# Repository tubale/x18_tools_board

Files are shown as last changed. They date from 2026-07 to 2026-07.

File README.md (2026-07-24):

# ROV Tools Board

A custom **4-layer STM32-based PCB** designed for Purdue IEEE Underwater Robotics to control a six-servo robotic arm. This project involved the complete hardware development cycle, including system architecture, schematic design, PCB layout, power distribution, board bring-up, debugging, and integration into the ROV.

---

## Overview

The Tools Board serves as the interface between the Raspberry Pi and the ROV's robotic arm. It provides reliable power delivery, real-time servo control, and SPI communication while operating in a high-current, electrically noisy environment.

This project was designed from the ground up using KiCad and assembled, tested, and validated on the team's underwater robot.

---

## Features

- Custom **4-layer PCB** designed in **KiCad**
- **STM32 microcontroller** for real-time control
- Controls **6 independent servo motors**
- Supports up to **4A peak current**
- High-efficiency **12V → 6V buck converter**
- **5V → 3.3V LDO** for the STM32 and logic circuitry
- **SPI communication** with Raspberry Pi
- Optimized PCB layout with isolated power planes for improved signal integrity
- Hand assembled and fully validated through hardware bring-up

---

## Hardware Architecture

```text
                 Raspberry Pi
                      │
                   SPI Interface
                      │
              ┌───────────────┐
              │   STM32 MCU   │
              └───────────────┘
          PWM │ │ │ │ │ │
              ▼ ▼ ▼ ▼ ▼ ▼
        ┌────────────────────┐
        │   6 Servo Outputs  │
        └────────────────────┘

12V Input
    │
    ▼
┌──────────────┐
│ Buck 12V→6V  │────────► Servos
└──────────────┘
    │
    ▼
┌──────────────┐
│ LDO 5V→3.3V  │────────► STM32 + Logic
└──────────────┘
```

---

## Design Process

### System Architecture

- Defined power and communication requirements
- Selected STM32 microcontroller
- Designed SPI interface with Raspberry Pi
- Planned high-current power distribution for servo operation

### Schematic Design

Designed the complete electrical schematic including:

- STM32 microcontroller
- Servo outputs
- SPI interface
- Programming/debug connector
- Buck converter
- LDO regulator
- Decoupling and filtering circuitry
- Status LEDs
- Connectors

### PCB Layout

Designed a **4-layer PCB** with:

- Dedicated ground plane
- Dedicated power plane
- High-current routing for servo power
- Short SPI signal paths
- Proper decoupling placement
- Separation between noisy power circuitry and sensitive digital signals

### Assembly

- Soldered surface-mount and through-hole components
- Inspected and verified board assembly
- Performed continuity testing before power-up

### Bring-Up & Validation

Verified each subsystem independently using:

- Digital Multimeter
- Oscilloscope
- Logic Analyzer

Testing included:

- Power rail verification
- SPI communication
- PWM generation
- Servo functionality
- Current measurements
- Signal integrity

---

### Technologies

**Hardware:** KiCad • STM32 • SPI • PWM • 4-Layer PCB Design • Buck Converter Design • LDO Voltage Regulation

**Testing:** Oscilloscope • Logic Analyzer • Digital Multimeter

---

## Gallery

### Schematic

<p align="center">
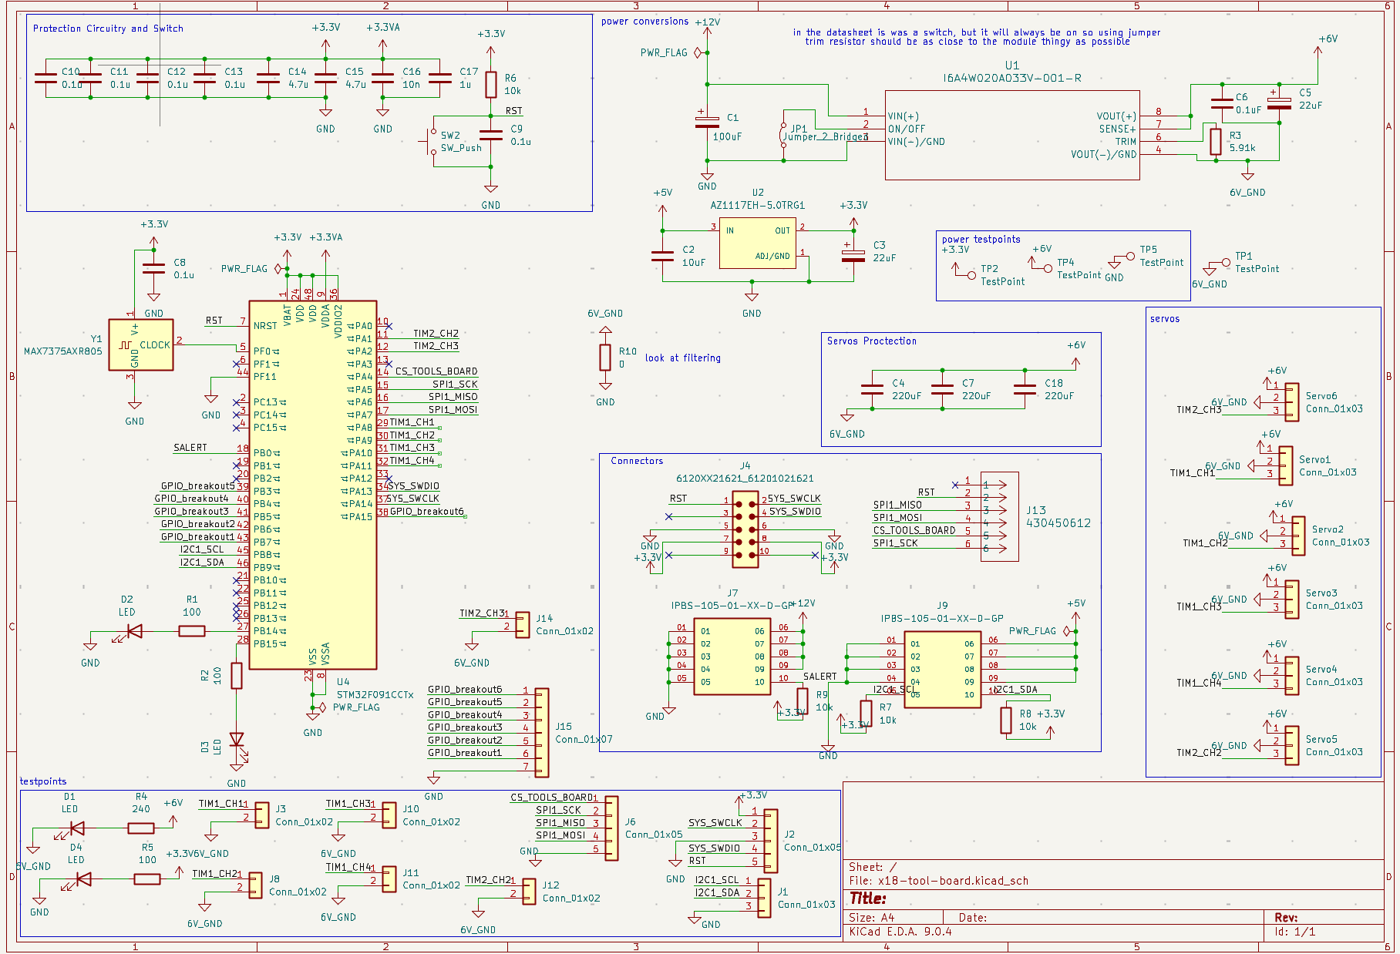
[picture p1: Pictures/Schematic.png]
  
</p>

### Layout

<p align="center">
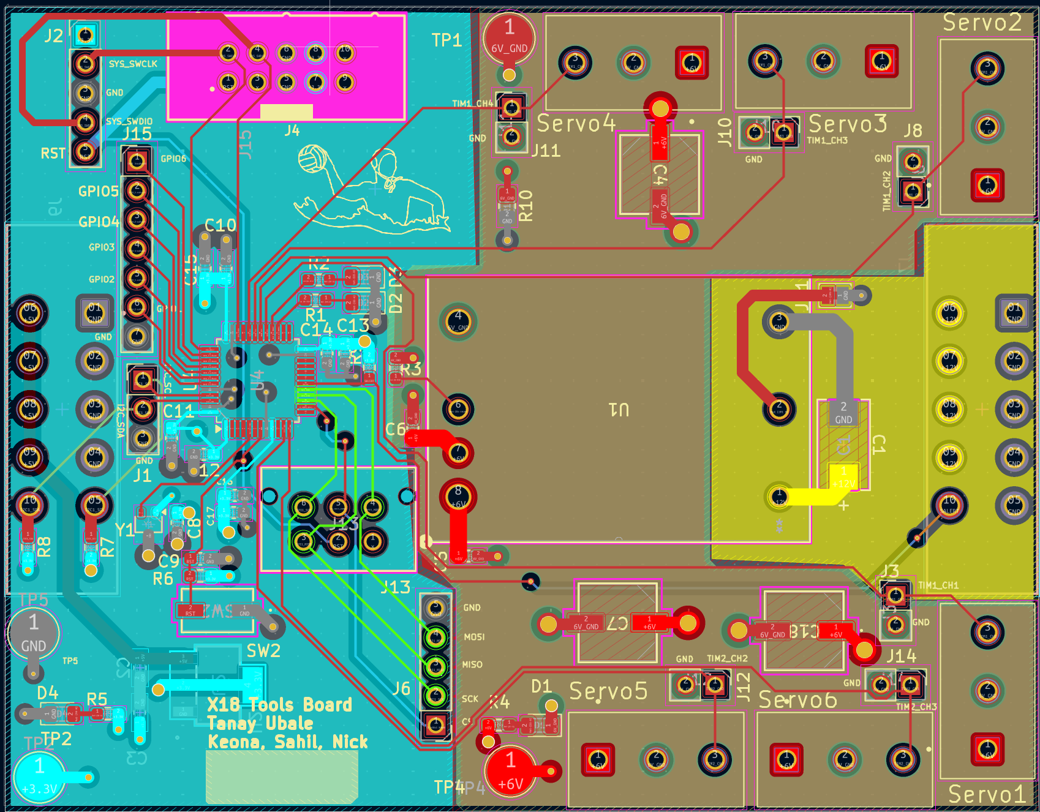
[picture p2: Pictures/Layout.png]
  
</p>

### Assembled Board

<p align="center">
  
</p>

---

## Author

**Tanay Ubale**

Electrical & Computer Engineering Student at Purdue University

Interested in Digital Design, FPGA Development, ASIC Design, Embedded Systems, PCB Design, and Computer Architecture.

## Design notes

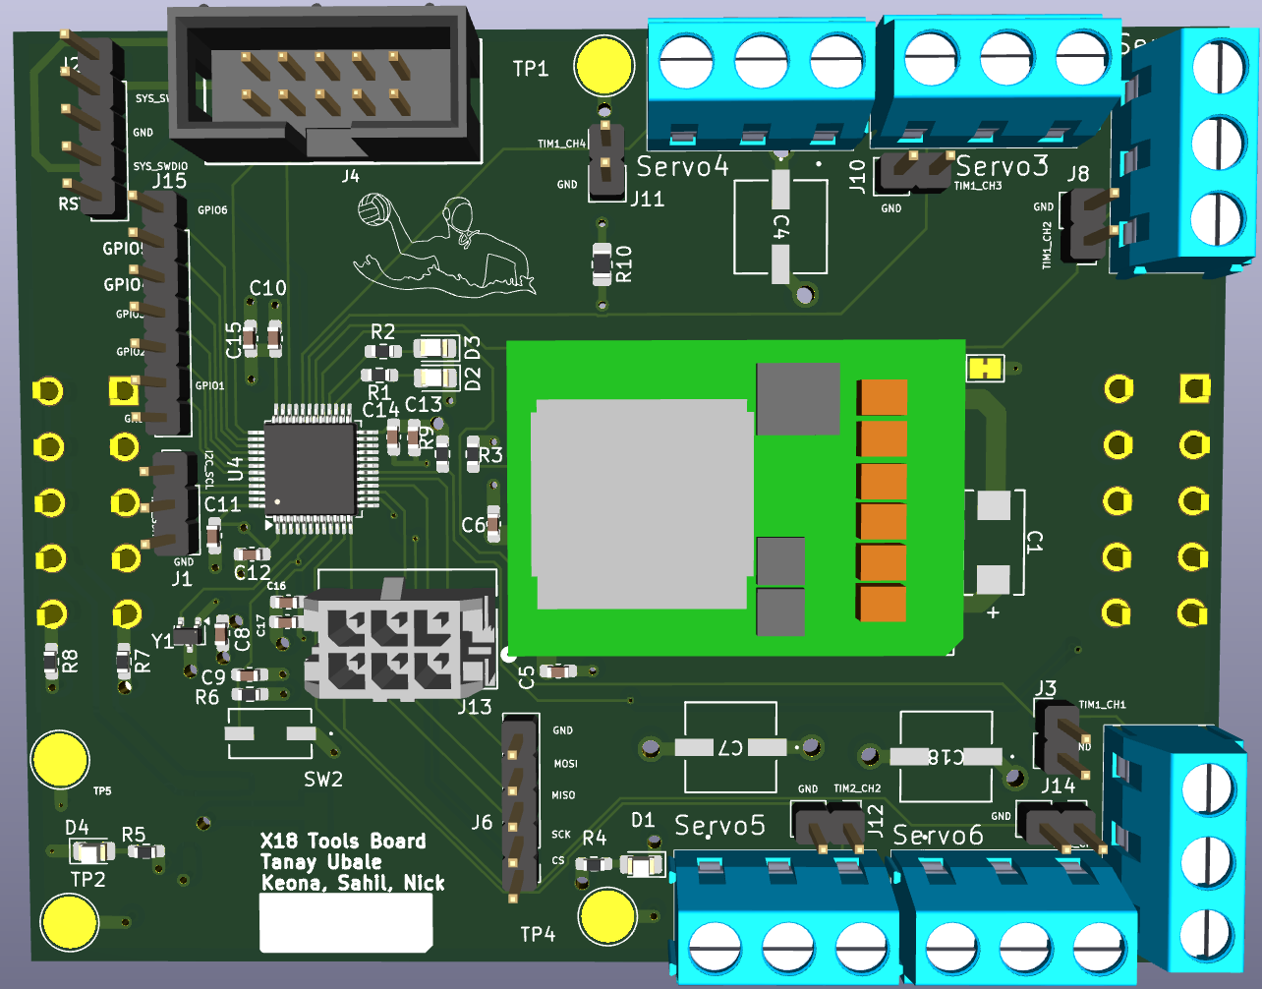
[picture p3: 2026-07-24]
Pictures/3d Model_front.png

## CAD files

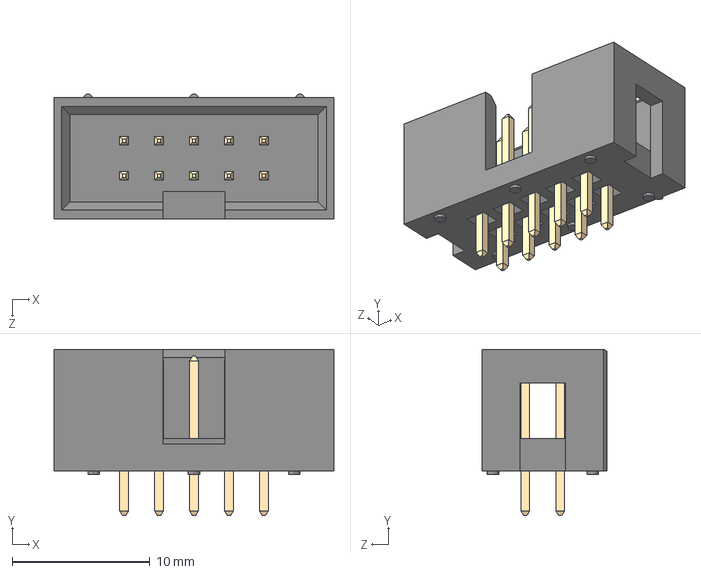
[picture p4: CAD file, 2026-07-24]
Footprints/61201021621/6120XX21621_61201021621.step
20.4 x 12.1 x 9.10 mm

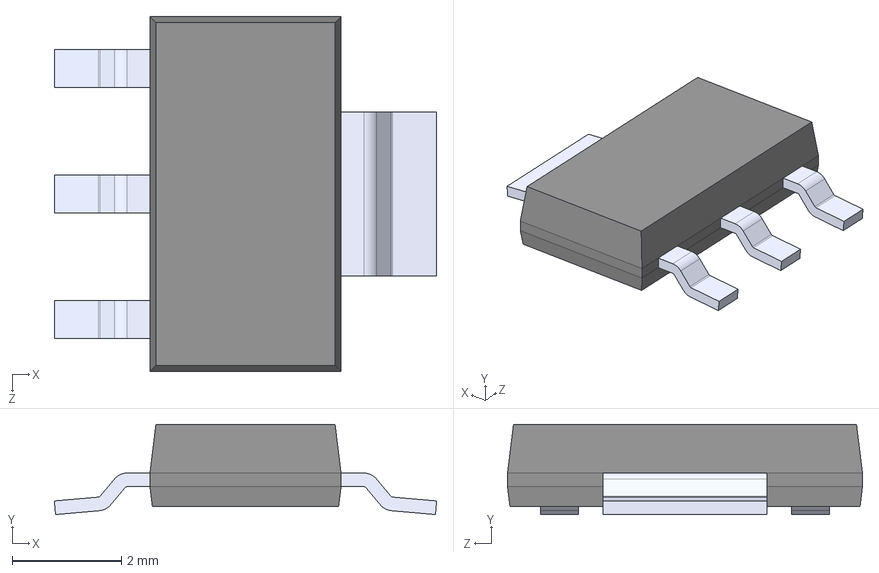
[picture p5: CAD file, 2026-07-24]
Footprints/AZ1117CH_3_3TRG1/AZ1117EH-5.0TRG1/AZ1117EH-5.0TRG1.step
7.00 x 1.65 x 6.50 mm

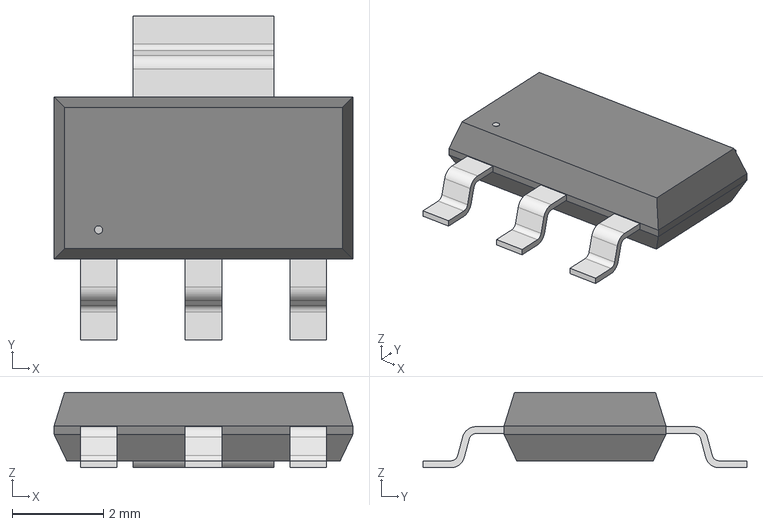
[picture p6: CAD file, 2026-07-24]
Footprints/AZ1117CH_3_3TRG1/SOT-223_DIO.step
6.55 x 7.10 x 1.65 mm

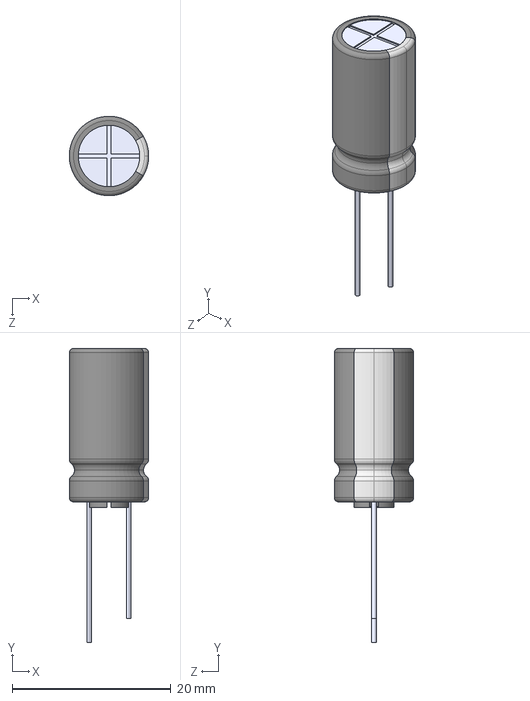
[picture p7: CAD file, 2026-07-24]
Footprints/EEU_FC1H221/EEUFC1H221.step
10.0 x 37.0 x 9.99 mm

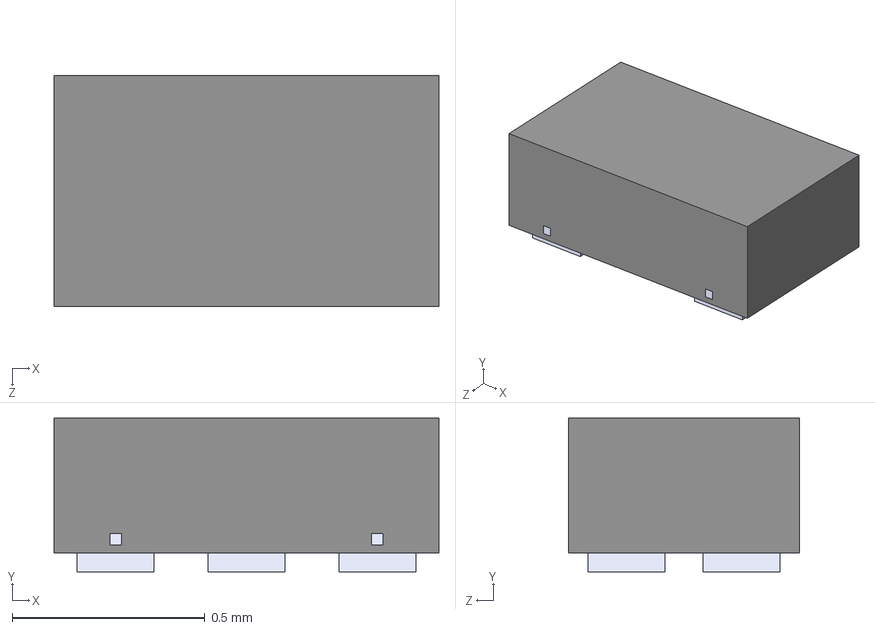
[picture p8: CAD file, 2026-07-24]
Footprints/ESD122DMXR/ESD122DMXR.step
1.00 x 0.4 x 0.6 mm

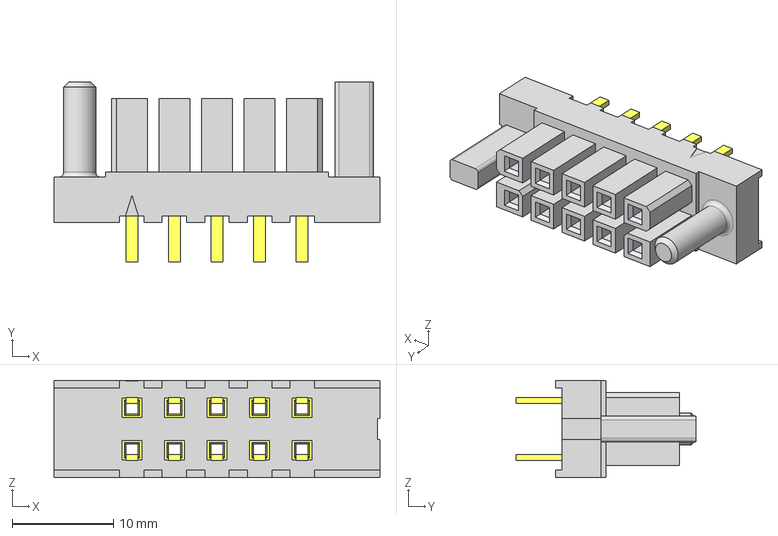
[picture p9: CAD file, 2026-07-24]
Footprints/IPBS-105-01-XX-D-GP/IPBS-105-01-XX-D-GP.step
32.1 x 17.8 x 9.60 mm
IPBS-105-XX-D-GP_socket
C-168-01-05-D

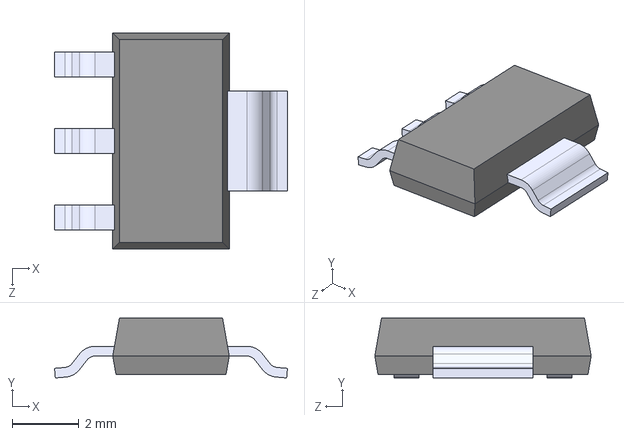
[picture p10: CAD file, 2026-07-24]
Footprints/LM3940/LM3940IMPX-3.3_NOPB.step
7.00 x 1.80 x 6.50 mm

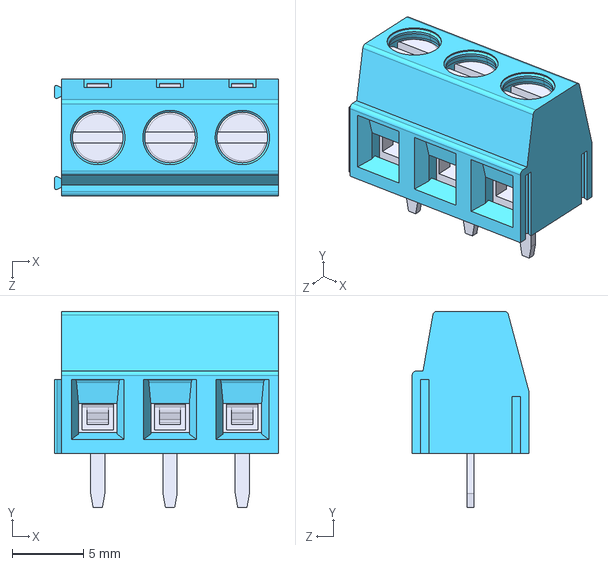
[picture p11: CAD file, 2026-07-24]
Footprints/TB006_508_03BE/TB006-508-03BE.step
15.7 x 13.8 x 8.20 mm

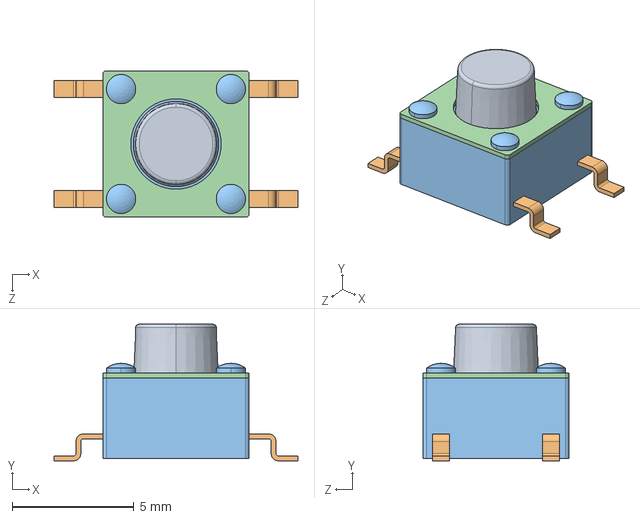
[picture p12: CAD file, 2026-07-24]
Footprints/TS04_66_55_BK_100_SMT/TS04-66-55-BK-100-SMT.step
10.0 x 5.60 x 6.00 mm

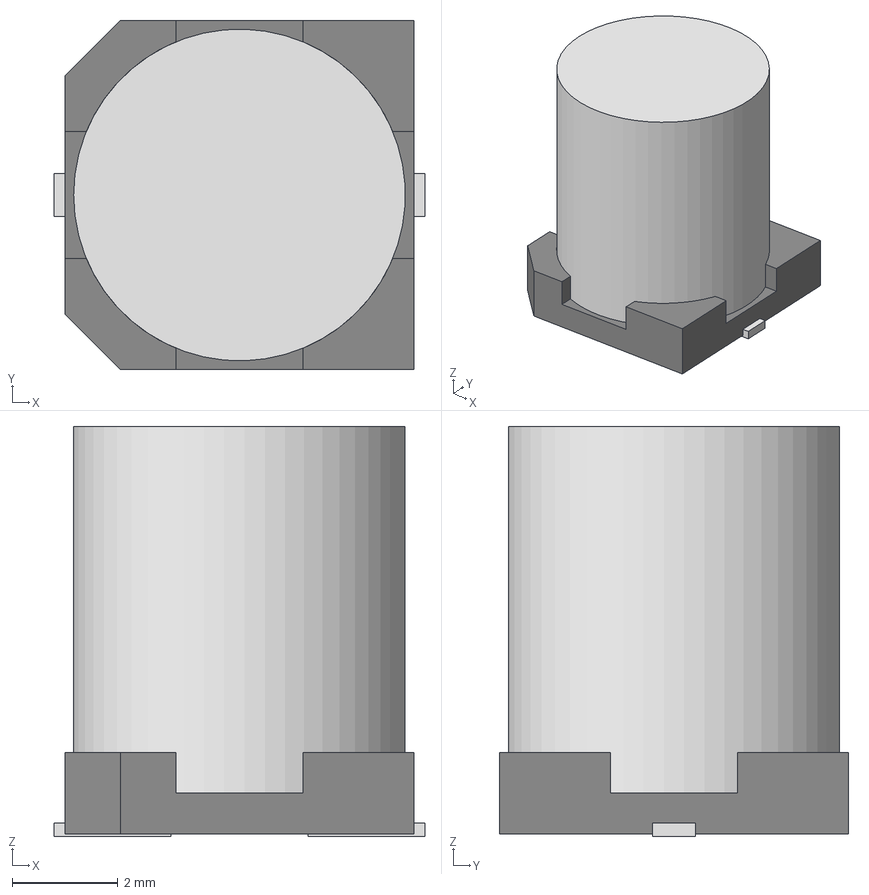
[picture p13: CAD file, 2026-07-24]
Footprints/ul_UWT1C221MCL1GS/U2-K_NCH.step
7.01 x 6.60 x 7.75 mm

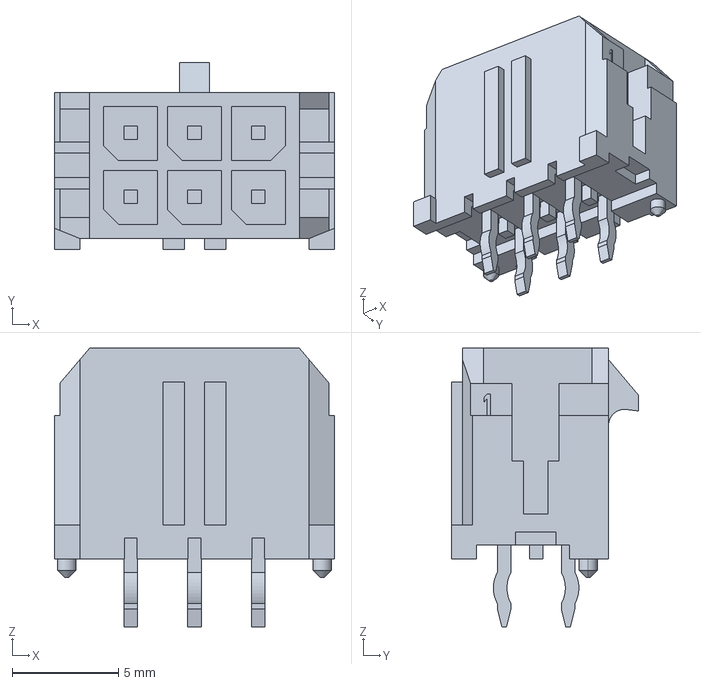
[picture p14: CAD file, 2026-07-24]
Footprints/430450612/430450612.stp
13.2 x 8.77 x 13.1 mm

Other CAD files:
Footprints/430450628/430450628.stp

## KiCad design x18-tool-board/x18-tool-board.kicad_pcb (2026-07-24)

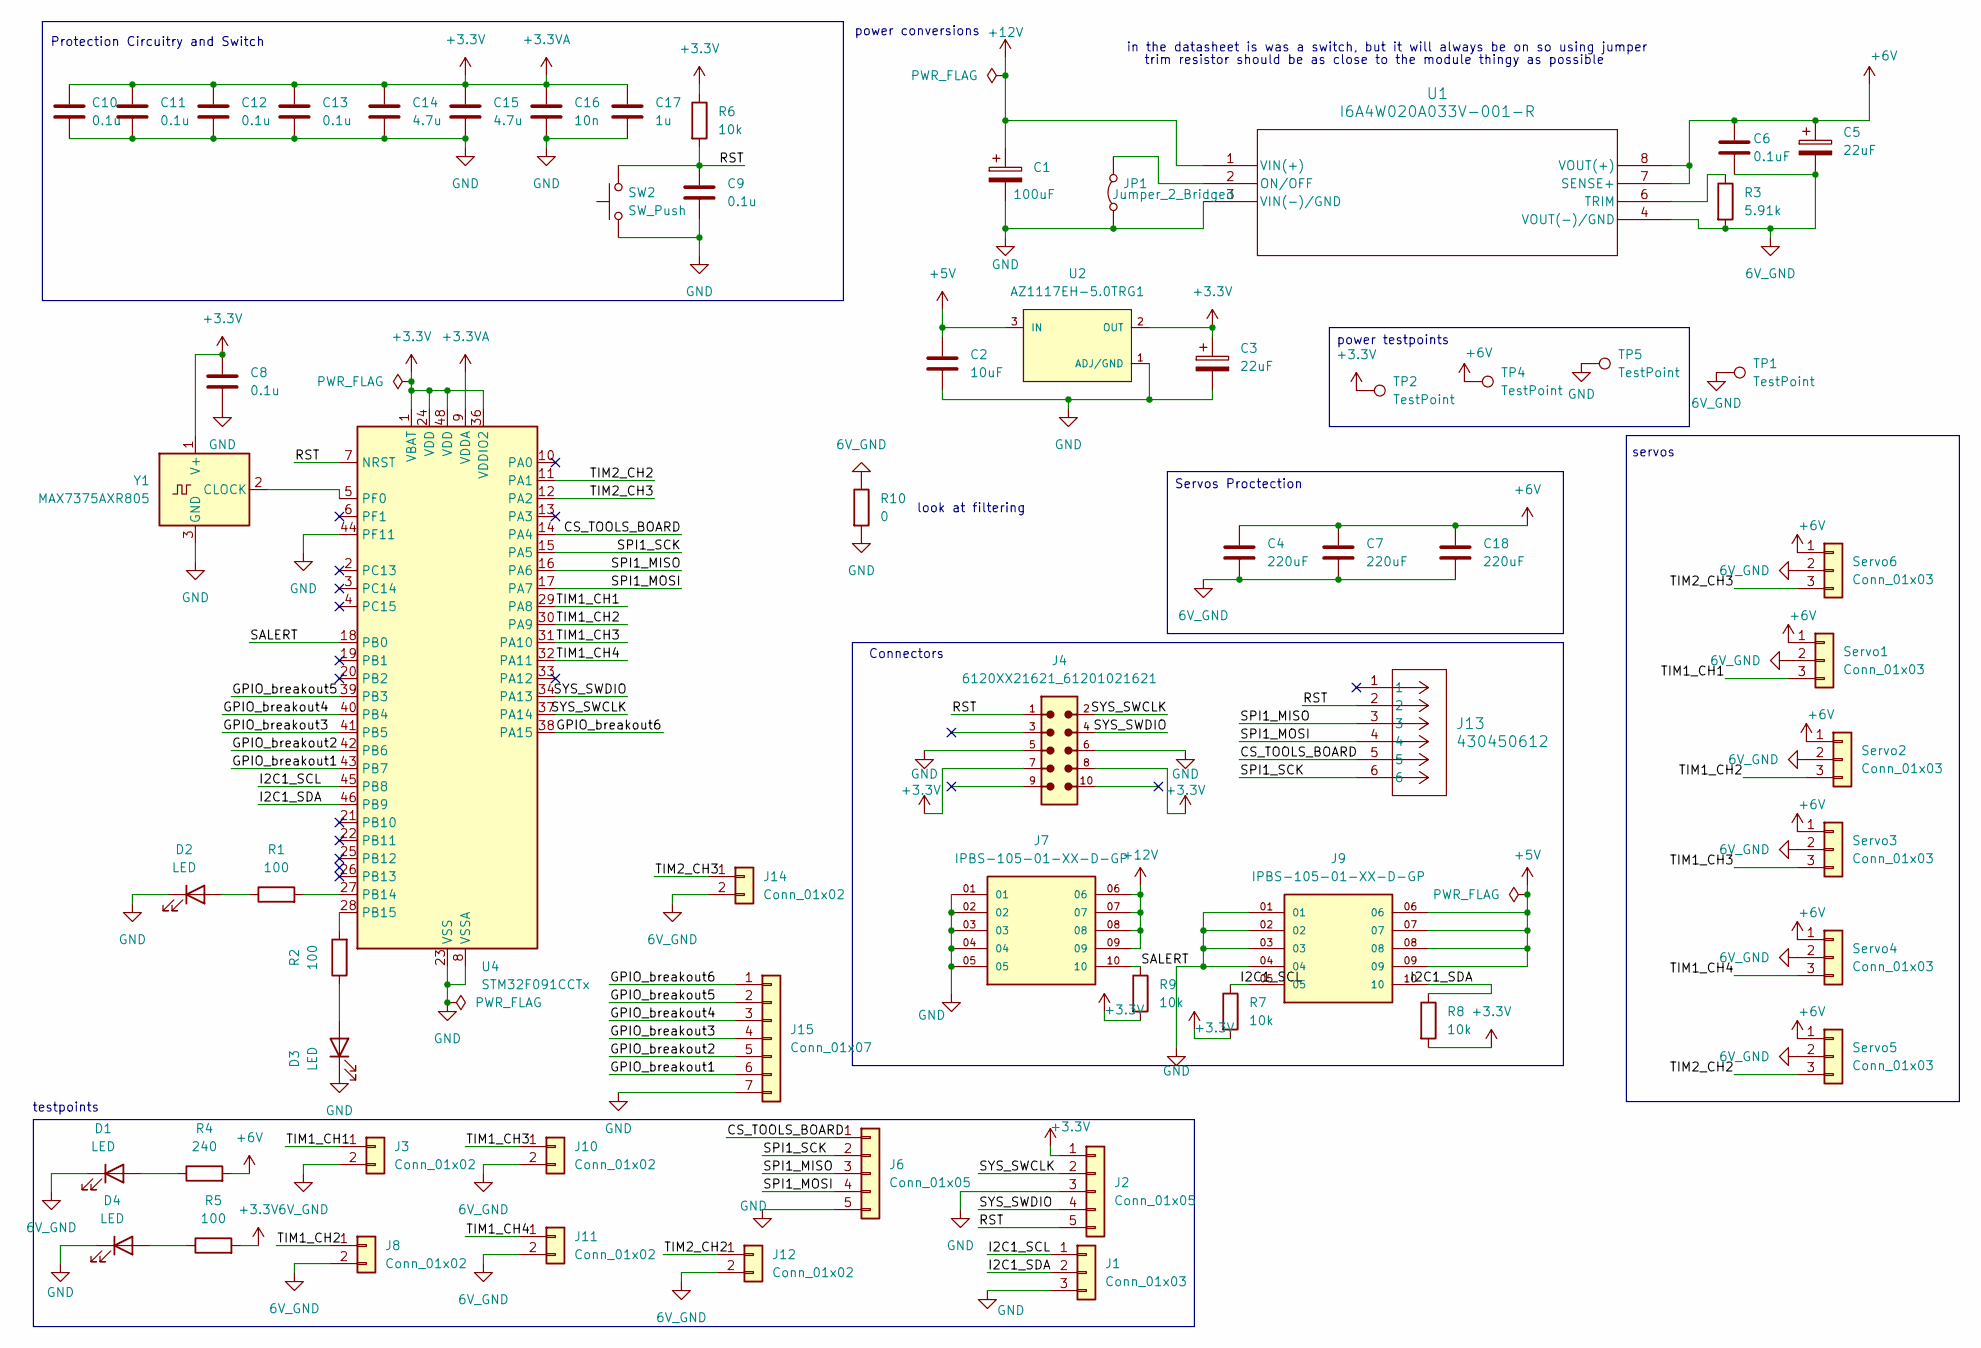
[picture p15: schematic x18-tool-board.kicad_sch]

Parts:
C1: 100uF; CAPMP7.6X4.3_4.3N_KEM-L
C2: 10uF; C_0603_1608Metric_Pad1.08x0.95mm_HandSolder
C3, C5: 22uF; C_0603_1608Metric_Pad1.08x0.95mm_HandSolder
C4, C7, C18: 220uF; U2-K_NCH-M
C6: 0.1uF; C_0603_1608Metric_Pad1.08x0.95mm_HandSolder
C8, C9, C10, C11, C12, C13: 0.1u; C_0603_1608Metric_Pad1.08x0.95mm_HandSolder
C14, C15: 4.7u; C_0603_1608Metric_Pad1.08x0.95mm_HandSolder
C16: 10n; C_0603_1608Metric_Pad1.08x0.95mm_HandSolder
C17: 1u; C_0603_1608Metric_Pad1.08x0.95mm_HandSolder
D1, D2, D3, D4: LED; LED_0805_2012Metric_Pad1.15x1.40mm_HandSolder
J1: Conn_01x03; PinHeader_1x03_P2.54mm_Vertical
J2, J6: Conn_01x05; PinHeader_1x05_P2.54mm_Vertical
J3, J8, J10, J11, J12, J14: Conn_01x02; PinHeader_1x02_P2.54mm_Vertical
J4: 6120XX21621_61201021621; 61201021621
J7, J9: IPBS-105-01-XX-D-GP; SAMTEC_IPBS-105-01-XX-D-GP; PARTREV M
J13: 430450612; CONN_SD-43045-005_06_MOL
J15: Conn_01x07; PinHeader_1x07_P2.54mm_Vertical
JP1: Jumper_2_Bridged; SolderJumper-2_P1.3mm_Bridged_Pad1.0x1.5mm
R1, R2, R5: 100; R_0603_1608Metric_Pad0.98x0.95mm_HandSolder
R3: 5.91k; R_0603_1608Metric_Pad0.98x0.95mm_HandSolder
R4: 240; R_0603_1608Metric_Pad0.98x0.95mm_HandSolder
R6, R7, R8, R9: 10k; R_0603_1608Metric_Pad0.98x0.95mm_HandSolder
R10: 0; R_0805_2012Metric_Pad1.20x1.40mm_HandSolder
SW2: SW_Push; SW_FSM2JMTR_TEC-M
Servo1, Servo2, Servo3, Servo4, Servo5, Servo6: Conn_01x03; CUI_TB006-508-03BE
TP1, TP2, TP4, TP5: TestPoint; TestPoint_Pad_D4.0mm
U1: I6A4W020A033V-001-R; i6A_TDK
U2: AZ1117EH-5.0TRG1; SOT-223_DIO
U4: STM32F091CCTx; LQFP-48_7x7mm_P0.5mm
Y1: MAX7375AXR805; SOT-323_SC-70

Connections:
6V_GND: C4.2, C5.2, C6.2, C7.2, C18.2, D1.1 (K), J3.2, J8.2, J10.2, J11.2, J12.2, J14.2, R3.2, R10.1, Servo1.2, Servo2.2, Servo3.2, Servo4.2, Servo5.2, Servo6.2, TP1.1, U1.4 (VOUT(-)/GND)
+3.3V: C3.1, C8.1, C10.1, C11.1, C12.1, C13.1, C14.1, C15.1, C16.1, C17.1, J2.1, J4.7, J4.8, R5.2, R6.1, R7.2, R8.2, R9.2, TP2.1, U2.2 (OUT), U2.4 (OUT), U4.1 (VBAT), U4.9 (VDDA), U4.24 (VDD), U4.36 (VDDIO2), U4.48 (VDD), Y1.1 (V+)
+5V: C2.1, J9.06, J9.07, J9.08, J9.09, U2.3 (IN)
+6V: C4.1, C5.1, C6.1, C7.1, C18.1, R4.2, Servo1.1, Servo2.1, Servo3.1, Servo4.1, Servo5.1, Servo6.1, TP4.1, U1.7 (SENSE+), U1.8 (VOUT(+))
+12V: C1.1, J7.06, J7.07, J7.08, J7.09, U1.1 (VIN(+))
/CS_TOOLS_BOARD: J6.1, J13.5, U4.14 (PA4)
/GPIO_breakout1: J15.6, U4.43 (PB7)
/GPIO_breakout2: J15.5, U4.42 (PB6)
/GPIO_breakout3: J15.4, U4.41 (PB5)
/GPIO_breakout4: J15.3, U4.40 (PB4)
/GPIO_breakout5: J15.2, U4.39 (PB3)
/GPIO_breakout6: J15.1, U4.38 (PA15)
/I2C1_SCL: J1.1, J9.05, R7.1, U4.45 (PB8)
/I2C1_SDA: J1.2, J9.10, R8.1, U4.46 (PB9)
/RST: C9.1, J2.5, J4.1, J13.2, R6.2, SW2.2, U4.7 (NRST)
/SALERT: J7.10, R9.1, U4.18 (PB0)
/SPI1_MISO: J6.3, J13.3, U4.16 (PA6)
/SPI1_MOSI: J6.4, J13.4, U4.17 (PA7)
/SPI1_SCK: J6.2, J13.6, U4.15 (PA5)
/SYS_SWCLK: J2.2, J4.2, U4.37 (PA14)
/SYS_SWDIO: J2.4, J4.4, U4.34 (PA13)
/TIM1_CH1: J3.1, Servo1.3, U4.29 (PA8)
/TIM1_CH2: J8.1, Servo2.3, U4.30 (PA9)
/TIM1_CH3: J10.1, Servo3.3, U4.31 (PA10)
/TIM1_CH4: J11.1, Servo4.3, U4.32 (PA11)
/TIM2_CH2: J12.1, Servo5.3, U4.11 (PA1)
/TIM2_CH3: J14.1, Servo6.3, U4.12 (PA2)
GND: C1.2, C2.2, C3.2, C8.2, C9.2, C10.2, C11.2, C12.2, C13.2, C14.2, C15.2, C16.2, C17.2, D2.1 (K), D3.1 (K), D4.1 (K), J1.3, J2.3, J4.5, J4.6, J6.5, J7.01, J7.02, J7.03, J7.04, J7.05, J9.01, J9.02, J9.03, J9.04, J15.7, JP1.1 (A), R10.2, SW2.1, TP5.1, U1.3 (VIN(-)/GND), U2.1 (ADJ/GND), U4.8 (VSSA), U4.23 (VSS), U4.35 (VSS), U4.44 (PF11), U4.47 (VSS), Y1.3 (GND)
unnamed: D1.2 (A), R4.1
unnamed: D2.2 (A), R1.1
unnamed: D3.2 (A), R2.1
unnamed: D4.2 (A), R5.1
unnamed: JP1.2 (B), U1.2 (ON/OFF)
unnamed: R3.1, U1.6 (TRIM)
unnamed: R1.2, U4.27 (PB14)
unnamed: R2.2, U4.28 (PB15)
unnamed: U4.5 (PF0), Y1.2 (CLOCK)

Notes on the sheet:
testpoints
servos
in the datasheet is was a switch, but it will always be on so using jumper
power conversions
trim resistor should be as close to the module thingy as possible
Connectors
look at filtering
Protection Circuitry and Switch
Servos Proctection
power testpoints

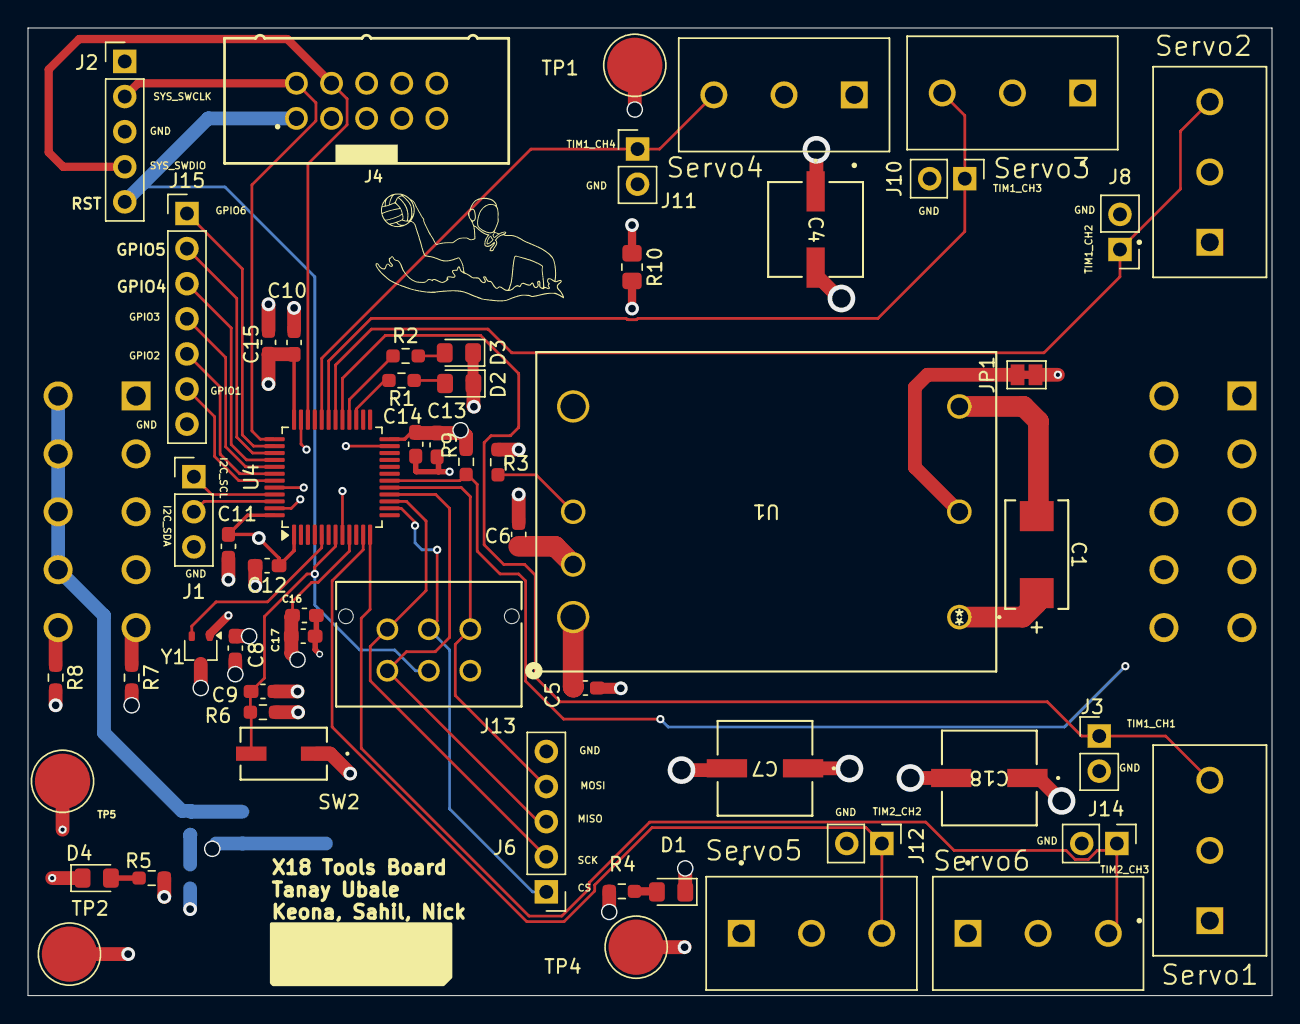
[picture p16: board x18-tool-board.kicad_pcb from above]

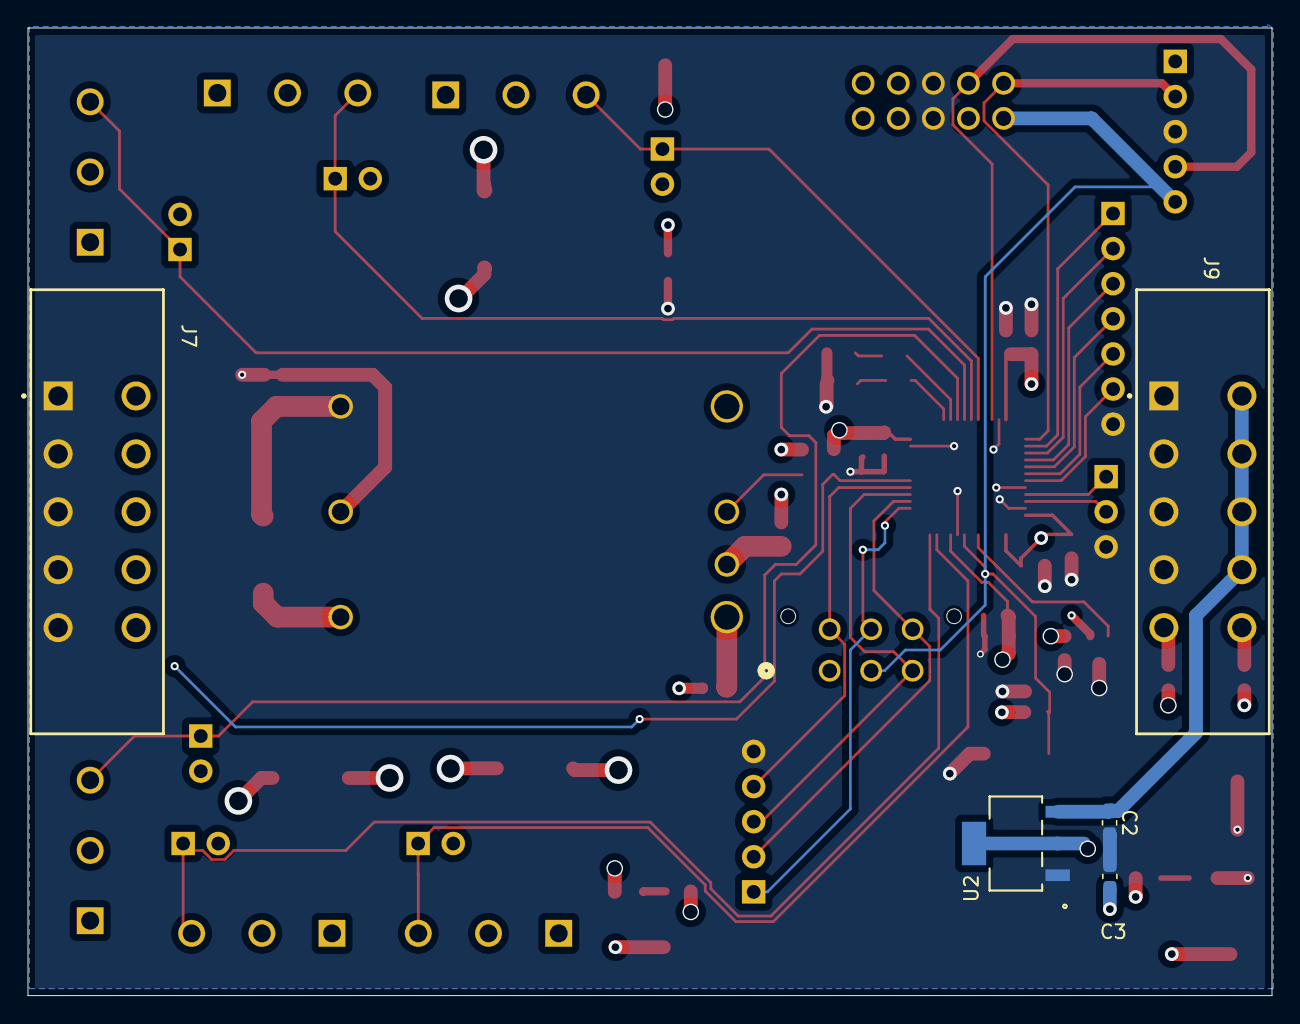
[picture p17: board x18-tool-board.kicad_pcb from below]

Board: 4 copper layers, 90.0 x 70.0 mm, 62 parts (5 on the bottom side), 37 nets.

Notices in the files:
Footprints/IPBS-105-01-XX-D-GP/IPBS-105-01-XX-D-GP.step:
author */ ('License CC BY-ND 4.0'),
